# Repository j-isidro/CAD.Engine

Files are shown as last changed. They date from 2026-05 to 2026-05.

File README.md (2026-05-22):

# 3D Printed Engine 

## Project Overview
This project involved the comprehensive design, analysis, and fabrication of a 1:7 scale internal combustion engine model. Working in a three-person team, we designed a crankshaft-piston assembly from scratch, performed thermodynamic and dynamic analysis, 3D printed all components in PLA, and competed against other teams in a formal RPM competition — **winning with a maximum rotation rate of 2,100 RPM**.

The engine was evaluated against the 2012 Ford Coyote 5.0L V8 using a power-to-size scoring formula, with the goal of maximizing horsepower and torque relative to engine volume.

### Final Assembly without the legs



---

## Objectives
- Analyze thermodynamic principles to determine optimal piston diameter, stroke length, and cylinder count
- Design a full crankshaft-piston assembly in SolidWorks including pistons, connecting rods, crankshaft, and engine block
- Perform SolidWorks motion simulation to generate velocity, acceleration, and displacement graphs
- Validate simulation results with hand calculations and free-body diagrams
- Conduct stress analysis on the connecting rod to determine factor of safety and optimal material selection
- Fabricate all components using PLA filament on Prusa 3D printers
- Survive a formal staged RPM test (300 → 600 → 900 RPM, then incrementally increased to failure or limit)

---

## Tools & Software
- **SolidWorks** — Part modeling, full assembly, motion simulation, stress analysis
- **Prusa Core One** — PLA filament 3D printing
- **Hand calculations** — Thermodynamic analysis, dynamic validation, stress and strain
- **High-RPM electric motor** — Formal competition testing apparatus

---

## Design Constraints
- Scale: 1:7 (must fit within a 2012 F-150 engine bay at scale)
- Max model size: 131 mm × 131 mm × 102 mm
- Min model size: 80 mm × 80 mm × 80 mm
- Bore: ≥ 13 mm diameter (1:7 scale)
- Stroke: ≥ 13 mm (1:7 scale)
- Max compression ratio: 14:1
- Material: PLA only, all hardware must be 3D printed
- Engine configuration: Must differ from V8, Flat 8, or Rotary

---

## Engineering Process

### Phase 1: Thermodynamic Analysis
- Calculated optimal bore, stroke, compression ratio, and piston count
- Determined horsepower and torque per piston and for the full engine
- Benchmarked theoretical performance against the 2012 Coyote 5.0L V8

### Phase 2: CAD Assembly
- Modeled all individual components in SolidWorks: pistons, connecting rods, crankshaft, connecting pins, and engine block
- Designed functional dynamic mates to simulate realistic engine motion
- Ensured crankshaft interface matched the competition testing device

### Phase 3: Motion Simulation & Hand Calculations
- Ran SolidWorks motion analysis to generate velocity, acceleration, and displacement graphs for the piston head
- Completed hand calculations for validation including free-body diagrams and kinetic diagrams for the crankshaft-piston assembly

### Phase 4: Stress Analysis
- Determined stress, strain, and factor of safety on the connecting rod at the piston head location
- Used results to justify material selection and identify design changes before printing

### Phase 5: Fabrication & Optimization 
Three major design iterations were completed before the final competition build:

**Iteration 1**
- Multiple failure points identified during informal testing
- Issues with cylinder fitment, crankshaft geometry, and mounting

**Iteration 2**
- Redesigned crankshaft using fused separate pieces
- Crankshaft fusion resolved some issues but mounting remained problematic

**Final Iteration**
- Squared crankshaft pins added to resist rotation and withstand torsional stress
- Crankshaft printed in separate parts proved efficient and effective
- Engine still experienced some connecting rod fusion during high-RPM testing

---

## Testing & Results
- **Formal test protocol:** Sustained 300 RPM for 30s → 600 RPM for 30s → 900 RPM for 60s
- **Maximum RPM achieved: 2,100 RPM** — highest in the class
- **Result: 1st place** in the formal engine competition
- Engine ultimately failed due to fusion of a connecting rod to the crankshaft, not wrist pin failure
- **Future improvement identified:** dried super glue between connecting rod and crankshaft to reduce friction and prevent fusion

[Watch the engine run at 900 RPM](https://drive.google.com/file/d/1uopaTeMAg6DidHOojKf3JH2RAt3dzKZa/view?usp=drive_link)
---

## Skills Demonstrated
- SolidWorks (part modeling, assemblies, motion simulation, stress analysis)
- Thermodynamic and dynamic engineering calculations
- 3D printing and iterative design
- Technical communication (poster presentation in class)
[Engine Project Poster.pdf](https://github.com/user-attachments/files/28160630/Engine.Project.Poster.pdf)



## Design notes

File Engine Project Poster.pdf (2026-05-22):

# SCHOOL OF ENGINEERING & COMPUTING

# Title: Model Boxer Engine Analysis

Section 1 Group 1
Authors: Nate Sullivan, Joseph Isidro, Michael Manduca, Philip Storti Advisor: Dr. Naser Haghbin

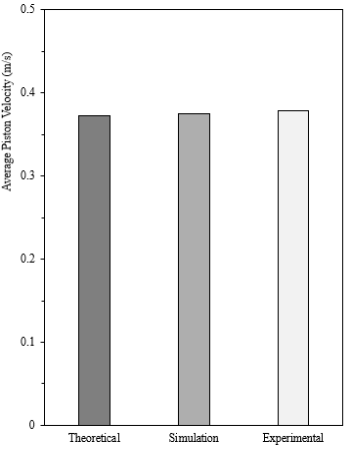
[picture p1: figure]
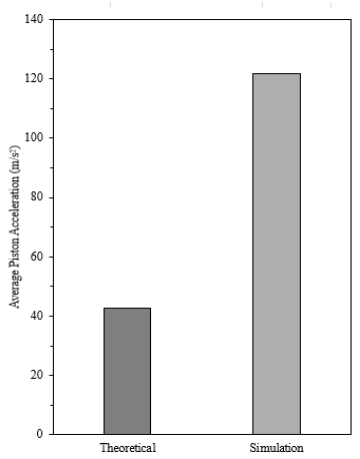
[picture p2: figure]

### PROJECT CONSTRAINTS AND REQUIREMENTS

### DESIGN PROCESS AND ITERATIONS

### RESULTS AND DISCUSSION

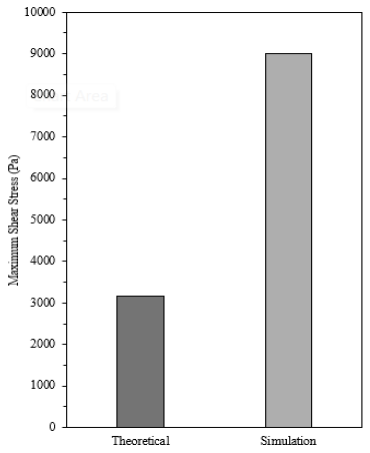
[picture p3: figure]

### CONCLUSIONS AND FUTURE WORK

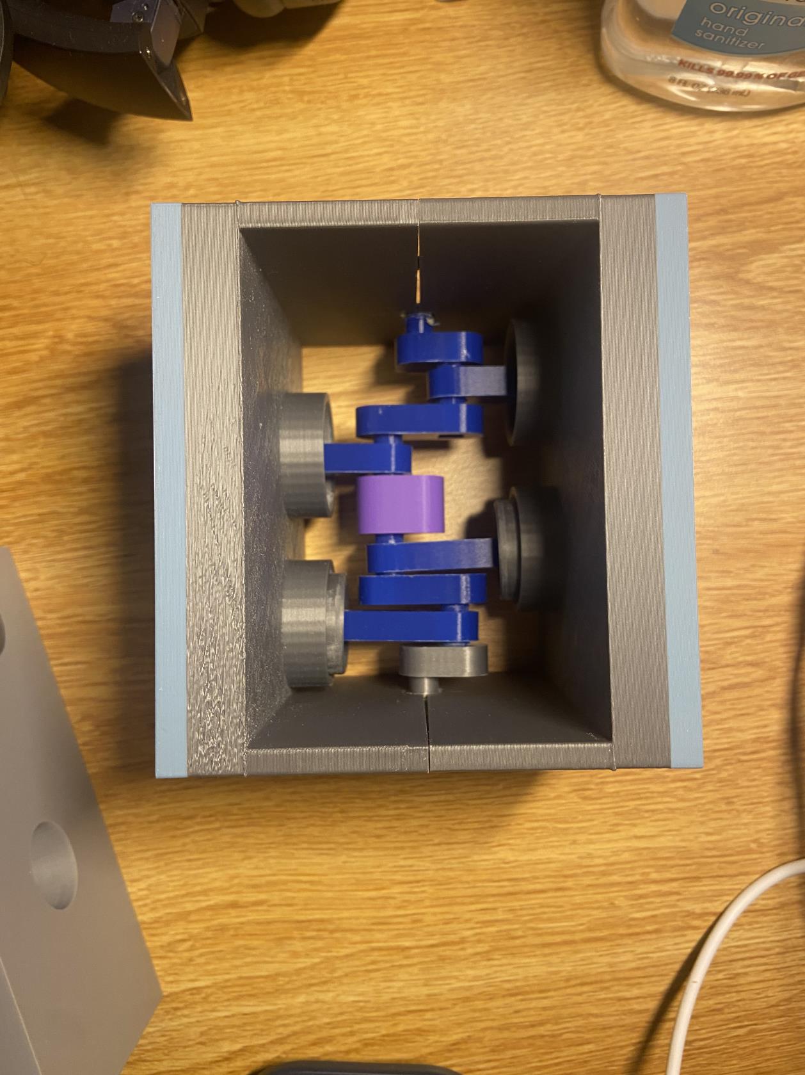
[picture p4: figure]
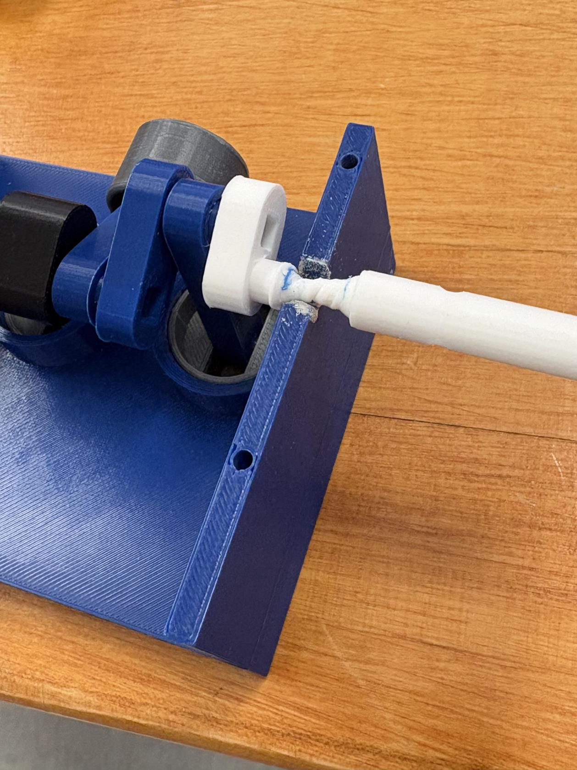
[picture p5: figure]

## 2026 Dynamics System Lab Mechanical Engineering Department

### BACKGROUND AND OBJECTIVE

- Design a crankshaft mechanism modeled after the Subaru EJ25
- Selected model for its over-square design (bore > stroke)
- Four-cylinder boxer with bore and stroke scaled down by a factor of 5
- Analyze kinematics of the piston mechanism
- Objective #1: sustain 900 RPM for the duration of a minute
- Objective #2: sustain a higher RPM than our peers
- Must fit within a scaled-down 2012 F-150 engine bay
- Cannot be an eight-cylinder system
- Fall within: 131 mm x 131 mm x 102mm and 80 mm x 80 mm x 80 mm
- Compression Ratio < 14:1
- Must safely mount and fit into the designated tester
- Must operate smoothly without the use of lubricants
- 4-cylinder boxer
- Crankshaft made from separate pieces
- Biggest jump was from prototype 1 to prototype 2
- First Iteration
- Multiple failing points
- Cylinder, fitment, crankshaft, etc.
- Second Iteration
- Crankshaft fusion
- Didn’t mount properly
- Final Iteration
- Still experienced fusion
- The model EJ25 was successful in maintaining a high RPM
- Crankshaft printed in parts proved to be efficient and effective
- Squared pins resisted rotation and withstood torsional stress
- Future improvement: dried super glue between the connecting rod and crankshaft to reduce friction and prevent fusion
- Reached a maximum of 2100 RPM
- Velocity, acceleration, and stress were analyzed at 900 RPM.
- Average velocity was similar across theoretical, simulation, and experimental analysis.
- Average acceleration and average stress found in the SolidWorks deviated from theoretical values.
- Engine did not fail due to failure of wrist pin, rather due to fusion of a connecting rod to the crankshaft.

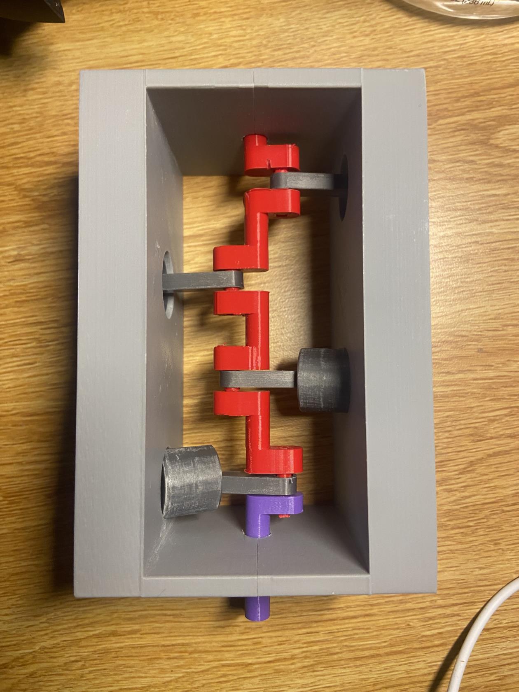
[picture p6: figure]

Fig. 1. Top view of first iteration. | Fig. 2. Top view of second iteration (post-test).

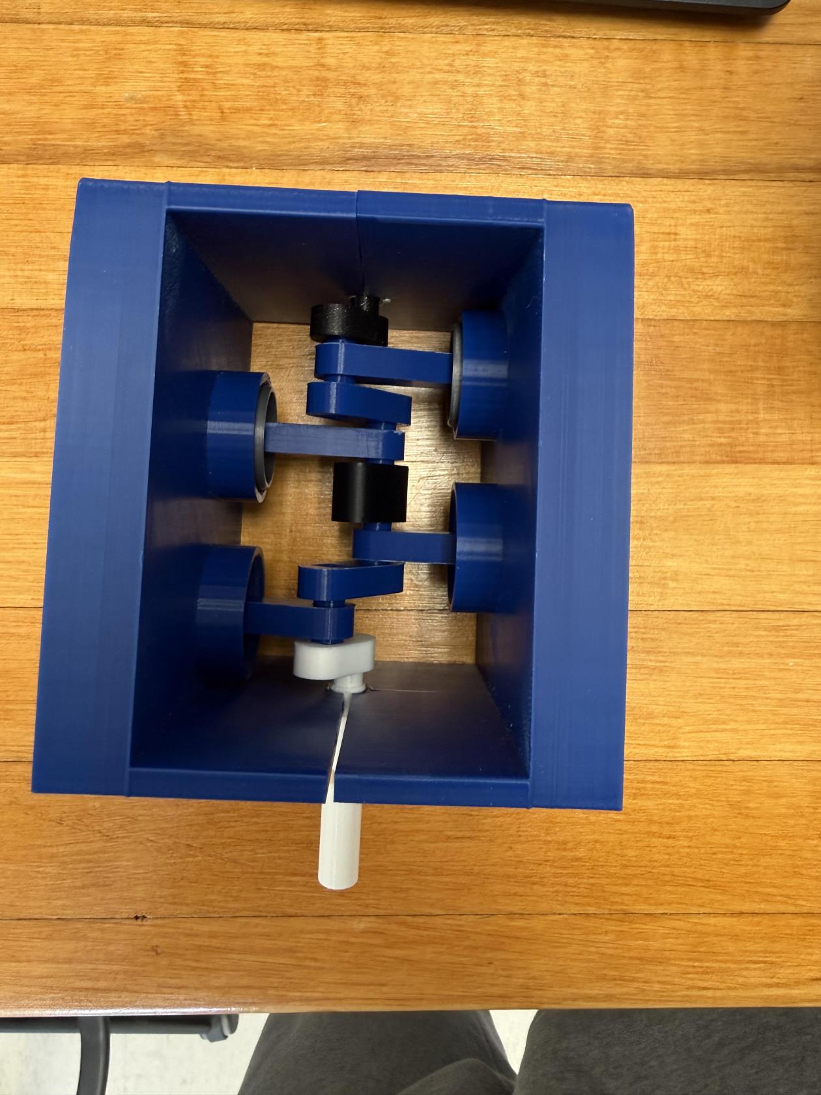
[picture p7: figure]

Fig. 3. Top view of final iteration (before test).

| Piston Count | Bore | Stroke | Compression Ratio | Ideal Power (HP) at 5500 RPM | Torque
Ford Coyote | 8 | 92.2 | 92.7 | 12 | 463.49 | 442.58
Subaru EJ-25 | 4 | 99.5 | 79 | 10 | 223.85 | 213.75
Our Boxer | 4 | 24.9 | 15.8 | 10 | 1.79 | 1.7100

Fig. 5. Average Piston Velocity comparison between
theoretical hand calculations, SolidWorks simulation, and experimental observation.

Fig. 6. Average Piston
Acceleration comparison
between theoretical hand
calculations and SolidWorks simulation.

Fig. 7. Maximum Shear Stress comparison between theoretical hand calculations and SolidWorks simulation. Shear stress was calculated on the wrist pin.

Table 1. Parameter comparison of Ford Coyote, Subaru EJ-25, and our model boxer engines.

Fig. 4. Failure of crankshaft (after test).

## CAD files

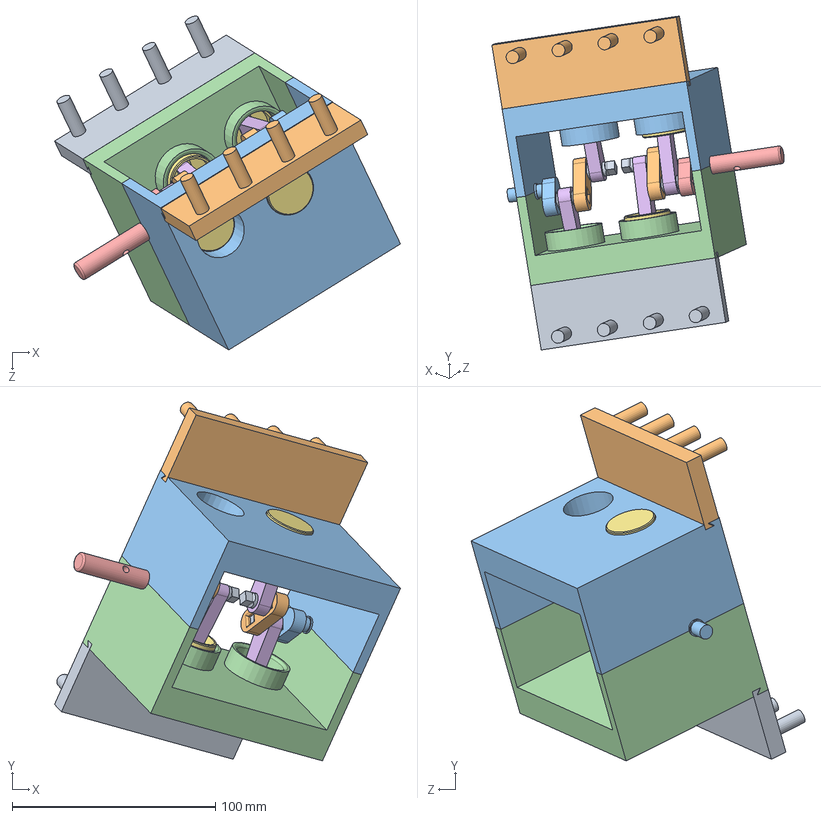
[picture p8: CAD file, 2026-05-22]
Engine_ThirdPrototype.SLDASM
170.1 x 176.4 x 164.2 mm
Engine_SixthPrototype_A
Engine_SixthPrototype_B x 2
Engine_ThirdPrototype_CrankPin x 4
Engine_FirstPrototype_WristPin x 4
Engine_SecondPrototype_PistonHead x 4
Engine_ThirdPrototype_ConnectingRod x 4
Engine_SeventhPrototype_A_v2
Engine_SixthPrototype_CaseFemaleHalf
Engine_SixthPrototype_CaseMaleHalf
Engine_FirstPrototype_SliderClamp
Engine_FirstPrototype_SliderClamp_Left

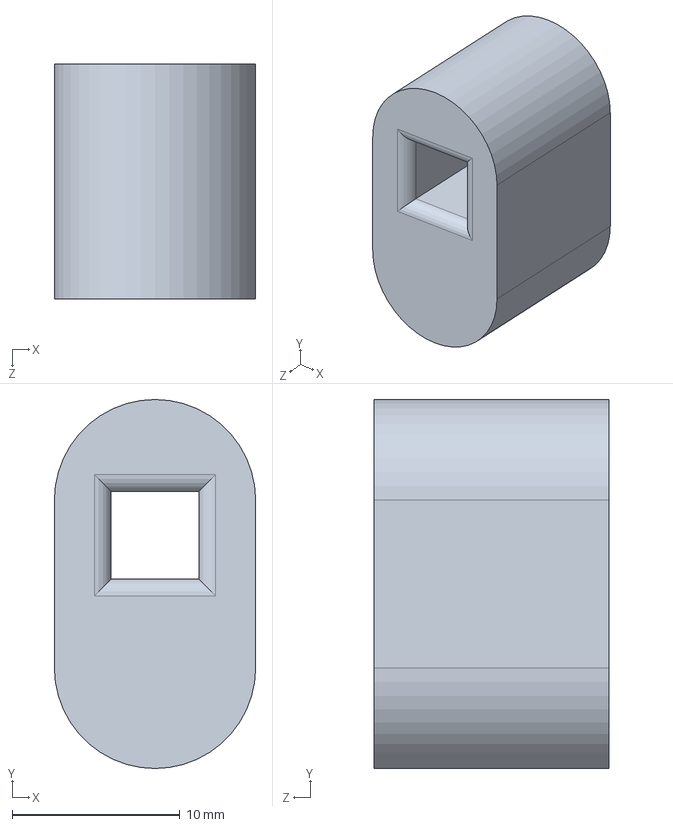
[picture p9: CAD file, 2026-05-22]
Engine_SeventhPrototype_C.SLDPRT
12.0 x 22.0 x 14.0 mm

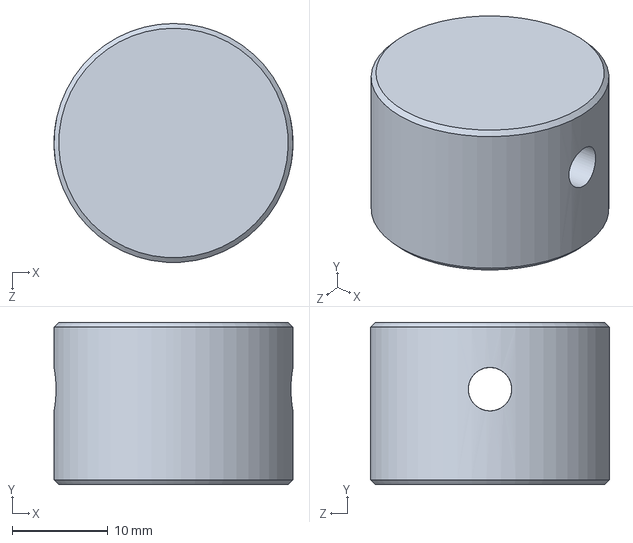
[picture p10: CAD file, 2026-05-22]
Engine_SecondPrototype_PistonHead.SLDPRT
24.9 x 16.9 x 24.9 mm

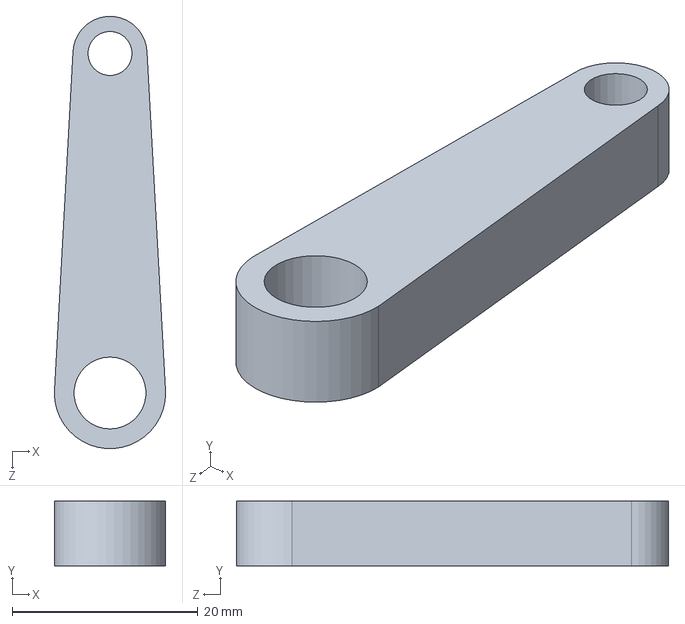
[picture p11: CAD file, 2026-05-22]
Engine_ThirdPrototype_ConnectingRod.SLDPRT
12.0 x 7.00 x 46.6 mm

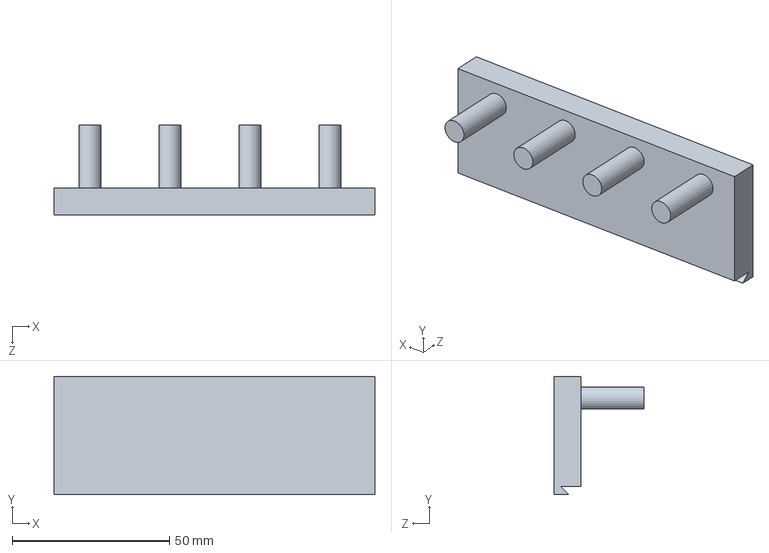
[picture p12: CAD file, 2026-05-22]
Engine_FirstPrototype_SliderClamp.SLDPRT
102.0 x 37.5 x 28.7 mm

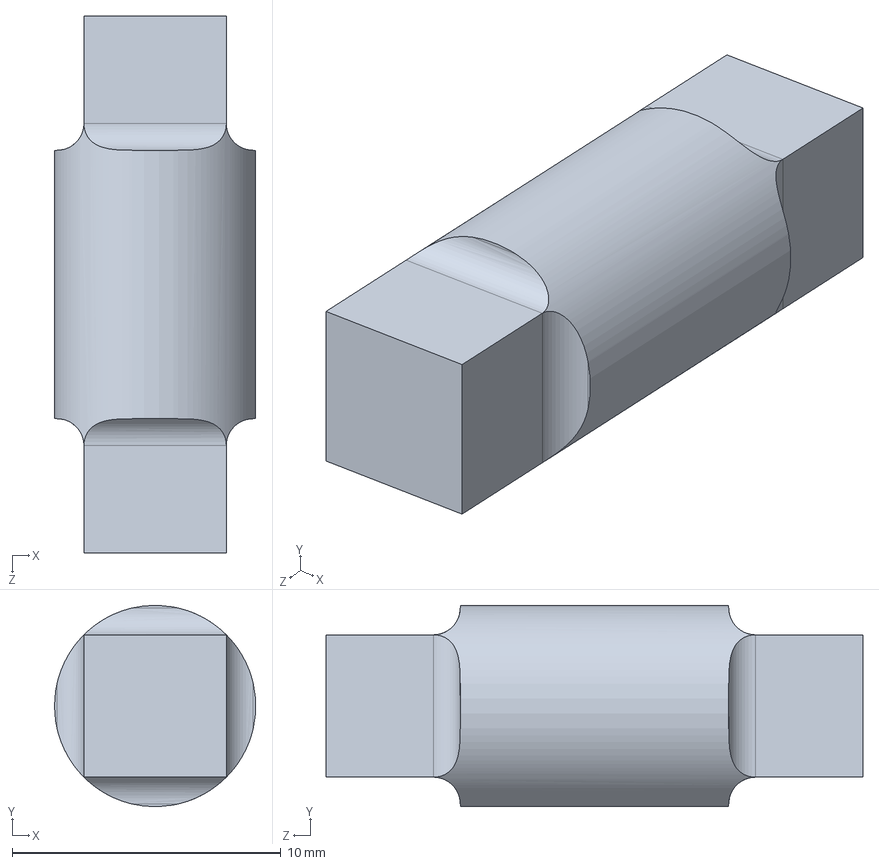
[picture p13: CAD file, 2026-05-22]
Engine_ThirdPrototype_CrankPin.SLDPRT
7.49 x 7.49 x 20.0 mm

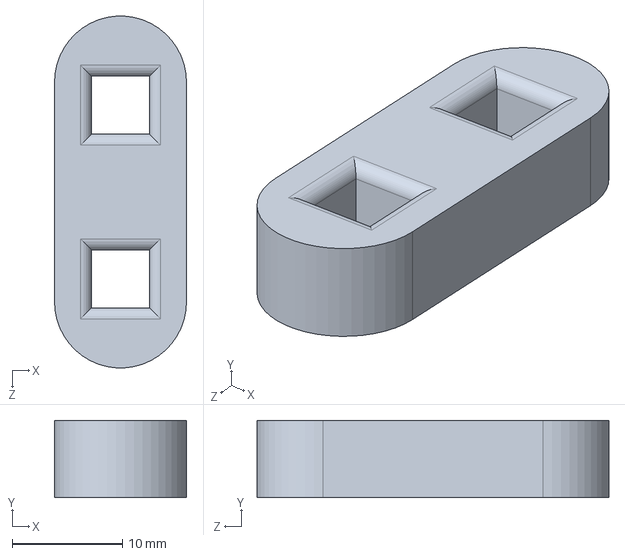
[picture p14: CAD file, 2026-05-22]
Engine_SixthPrototype_B.SLDPRT
12.0 x 7.00 x 32.0 mm

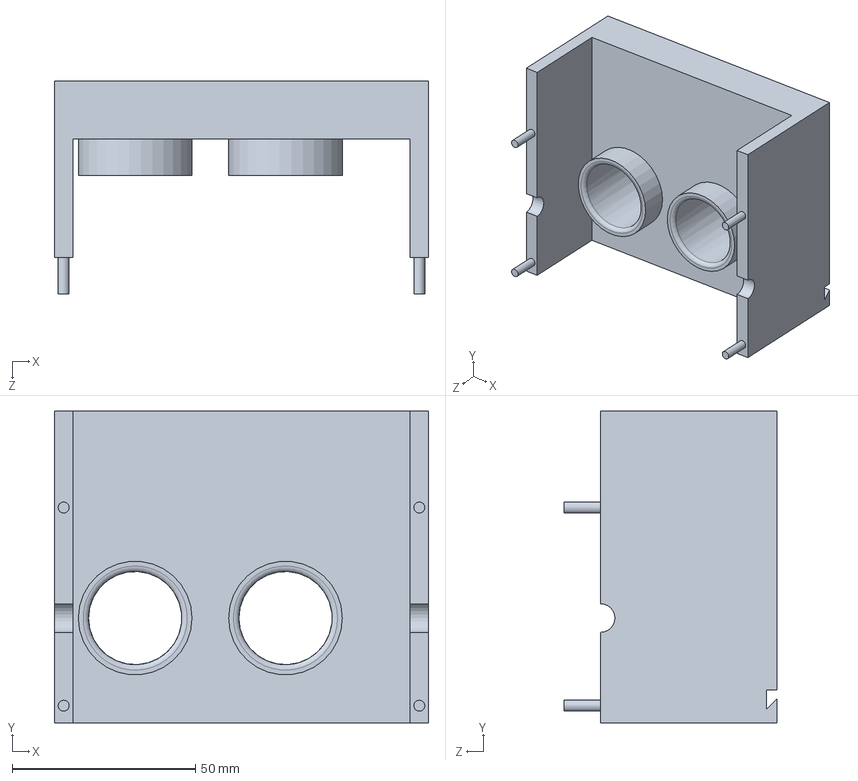
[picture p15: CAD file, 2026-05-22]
Engine_SixthPrototype_CaseMaleHalf.SLDPRT
102.0 x 85.0 x 58.1 mm

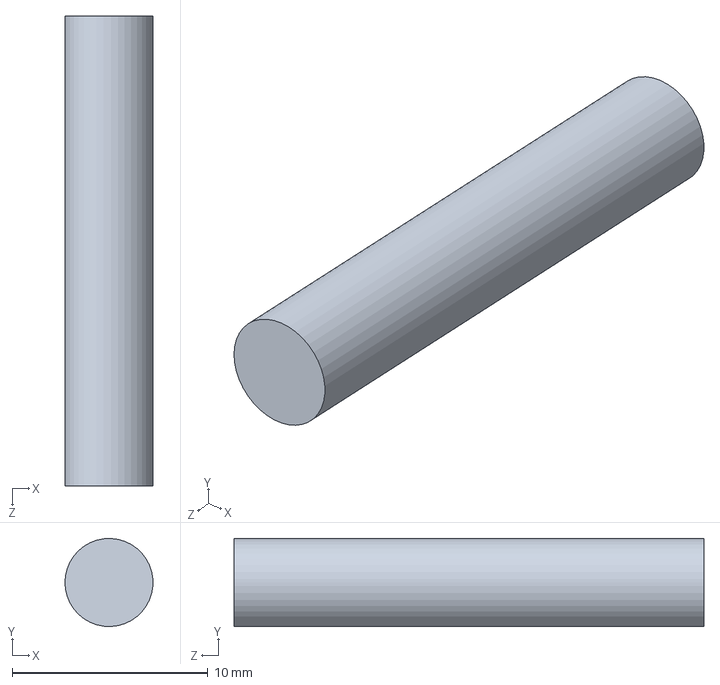
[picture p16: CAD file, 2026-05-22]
Engine_FirstPrototype_WristPin.SLDPRT
4.50 x 4.50 x 24.0 mm

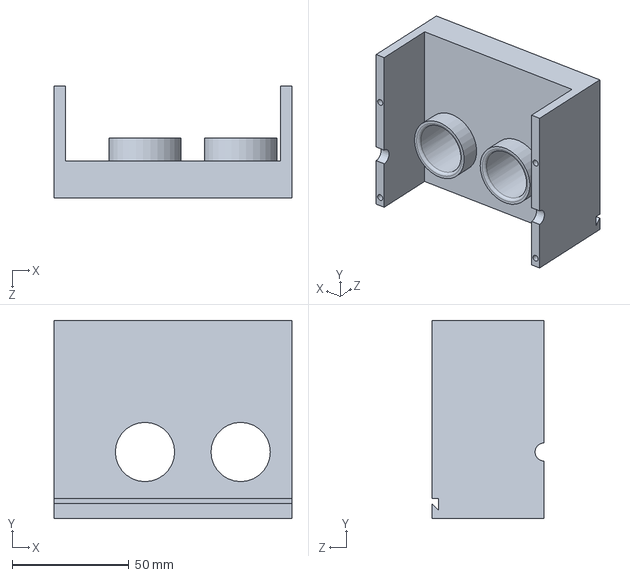
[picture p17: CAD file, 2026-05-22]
Engine_SixthPrototype_CaseFemaleHalf.SLDPRT
102.0 x 85.0 x 48.1 mm

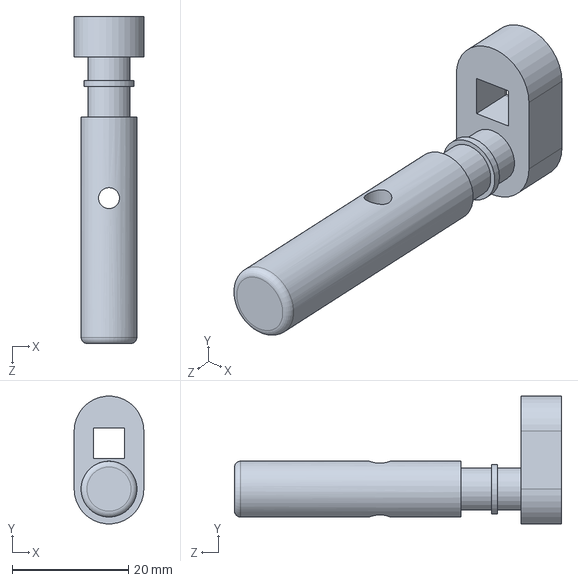
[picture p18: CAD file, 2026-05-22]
Engine_SeventhPrototype_A_v2.SLDPRT
12.0 x 21.9 x 56.2 mm

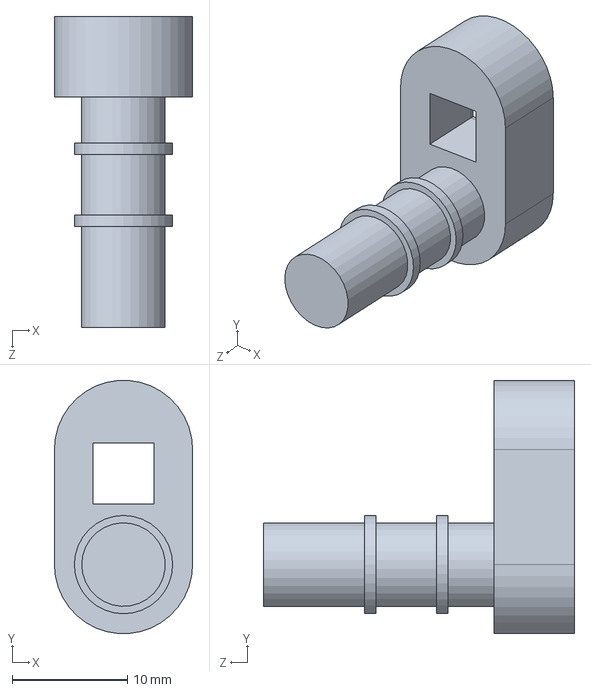
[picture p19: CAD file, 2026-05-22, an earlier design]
Engine_SixthPrototype_A.SLDPRT
12.0 x 22.0 x 27.0 mm

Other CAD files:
Engine_FirstPrototype_SliderClamp_Left.SLDPRT
Engine_SixthPrototype_C-1.SLDPRT
